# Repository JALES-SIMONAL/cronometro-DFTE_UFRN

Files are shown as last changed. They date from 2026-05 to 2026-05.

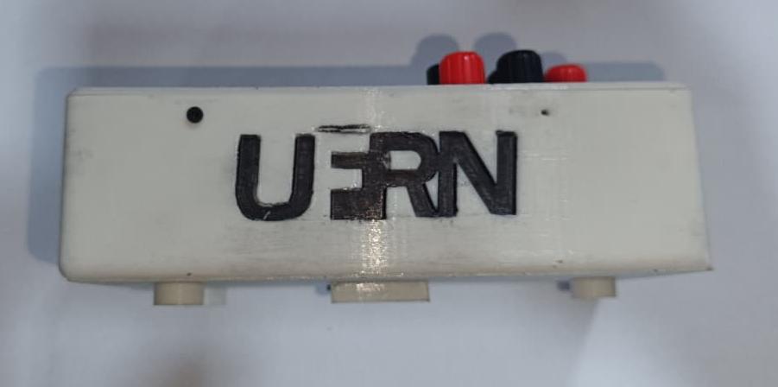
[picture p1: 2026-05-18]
Fotos/Hardware de aquisição de dados visão lateral.jpeg

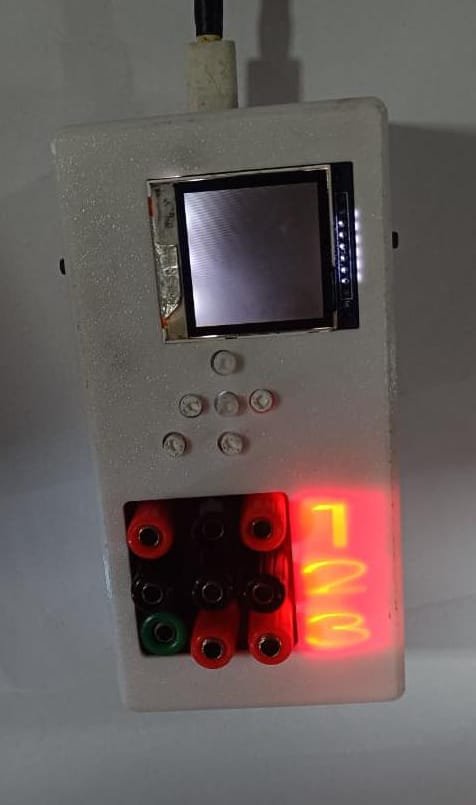
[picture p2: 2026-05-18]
Fotos/hardware de aquisição em modo de teste.jpeg

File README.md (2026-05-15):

# Cronômetro DFTE_UFRN

Este repositório contém um cronômetro digital de uso laboratorial, desenvolvido para o Departamento de Física Teórica e Experimental da UFRN. O projeto utiliza Arduino/ESP32, com o código principal em arquivo `.ino`, e peças impressas em 3D para montagem do gabinete.

---

## Principais características do arquivo .ino (Arduino/ESP32)

- **Linguagem/Compatibilidade**: Código em C++ próprio para Arduino, ESP32 ou similares.
- **Estrutura típica**:
    - Definição de pinos para botões, display, LEDs, etc.
    - Inicialização de periféricos no `setup()`.
    - Loop principal para leitura de botões e atualização do display.
    - Funções auxiliares para debounce, controle de estado, e lógica de contagem.
- **Operações suportadas:**
    - Iniciar, pausar e resetar o cronômetro.
    - Exibição precisa do tempo (até milissegundos, se desejado).
    - Indicação visual (LEDs, display) e sonora (se houver buzzer).
- **Flexível e comentado:** Fácil adaptação do código e documentação com comentários para aprendizado ou modificações.

---

## Lista de Componentes Eletrônicos

| Qtde | Descrição | Designador | Fabricante/Supplier | Parte/Fabricante | Código LCSC |
|---|---|---|---|---|---|
| 1 | ESP32 DEVKITV1 | - | - | ESP32-DEVKITV1 | - |
| 1 | Suporte p/ Bateria 18650 | U12 | - | BAT_BOX | C9900015078 |
| 1 | Regulador de Tensão | U4 | - | 134N3P COPY | - |
| 9 | Conector Banana (painel) | U1-U3, U6-U11 | - | Any Banana Jack | - |
| 1 | Conector 2P KH-PH-2P-Z | CN1 | kinghelm | KH-PH-2P-Z | C2898945 |
| 3 | Capacitor 0805 | C1, C2, C3 | - | - | - |
| 3 | LED RGB WS2812B-5050 | LED1-LED3 | - | WS2812B-5050RGB | C2838584 |
| 6 | Push button 6x6x7mm | KEY1-KEY6 | ReliaPro | 6*6*7 | C69055 |
| 1 | Módulo LCD 1.8" | LCD1 | Waveshare | 1.8INCH LCD MODULE | C359940 |
| 4 | MOSFET LBSS138LT1G-VB | Q1-Q4 | VBsemi | LBSS138LT1G-VB | C7429063 |
| 9 | Resistor 0805 10k | R1, R2-R9 | - | 0805_10k | C9900012714 |
| 1 | Chave CN-KCD1-101-2P | SW1 | - | CN-KCD1-101-2P | C9900002516 |

> Consulte a BOM completa para detalhes adicionais: `BOM_PhotoGate_Controlador_2026-05-15.csv`.

---

## Lista de Peças para Impressão 3D

1. **Gabinete Principal:** Estrutura para acomodar o ESP32, LCD, botões e conectores.
2. **Frontal do Gabinete:** Painel com janelas/furos para display, LEDs e botões.
3. **Tampa Traseira:** Fecho para o gabinete, com furos para fixação se necessário.
4. **Suporte para a bateria 18650:** (opcional, conforme design).
5. **Botões personalizados para painel:** (opcional, melhor ergonomia/estética).
6. **Bases ou pés para apoio:** (opcional, estabilidade em bancada).

> Os arquivos STL necessários para impressão estarão na pasta `/impressao_3d` deste repositório.

---

## Montagem e Funcionamento

1. **Imprima as peças 3D** conforme necessário.
2. **Monte o ESP32, display e botões** no gabinete impresso.
3. **Realize a ligação dos botões, display e LEDs** de acordo com o que está especificado no `.ino` e na tabela de componentes.
4. **Alimente o circuito** via USB ou bateria (18650, conforme montagem).
5. **Carregue e rode o código** na ESP32 usando a IDE Arduino.
6. **Operação**: utilize os botões para iniciar, pausar ou resetar. O tempo será mostrado no LCD, e LEDs poderão sinalizar o status.

---

## Recomendações e Observações

- Confirme o mapeamento dos pinos entre hardware e código.
- Use resistores de pull-down nos botões para evitar disparos falsos.
- Realize testes antes de fechar o gabinete definitivamente.
- Adapte o código caso utilize um display/módulo diferente.
- Instale quaisquer bibliotecas necessárias na IDE Arduino antes do upload.

---

## Licença

[uso livre]

---

**Dúvidas, sugestões ou problemas?**  
Abra uma issue neste repositório.

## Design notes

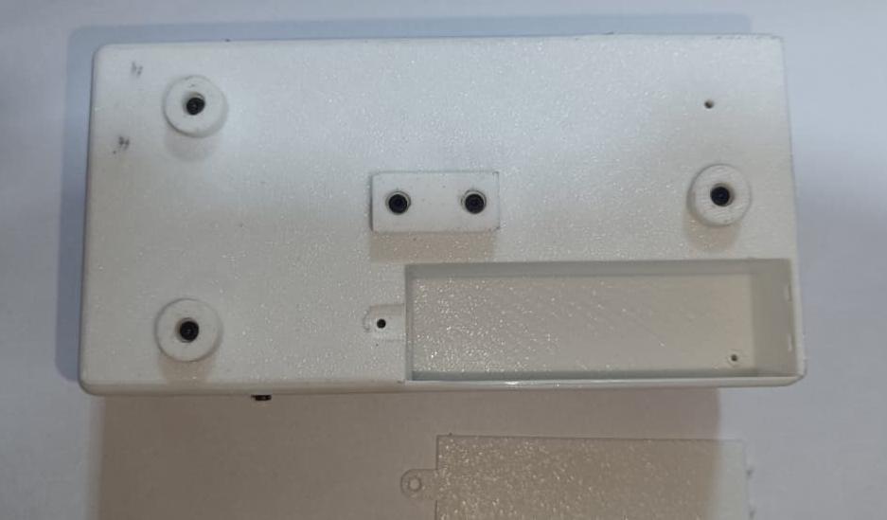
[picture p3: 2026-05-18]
Fotos/Hardware de aquisição de dados visão posterior.jpeg

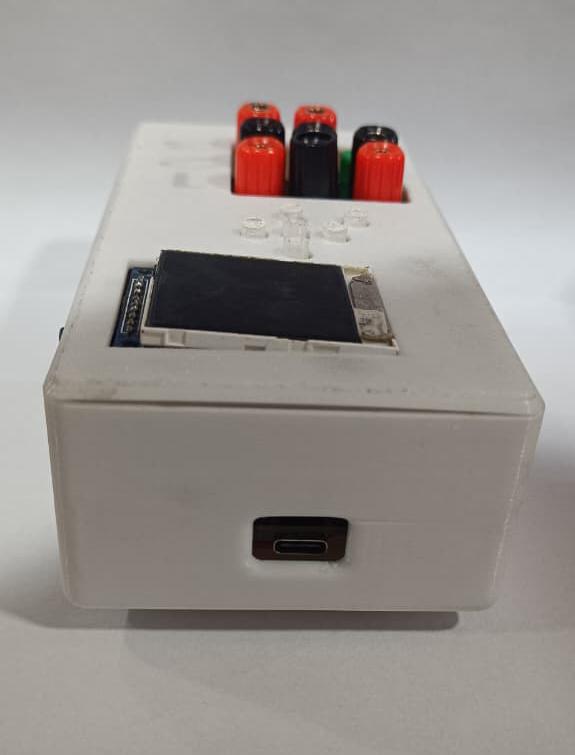
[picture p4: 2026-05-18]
Fotos/Hardware de aquisição de dados visão superior.jpeg

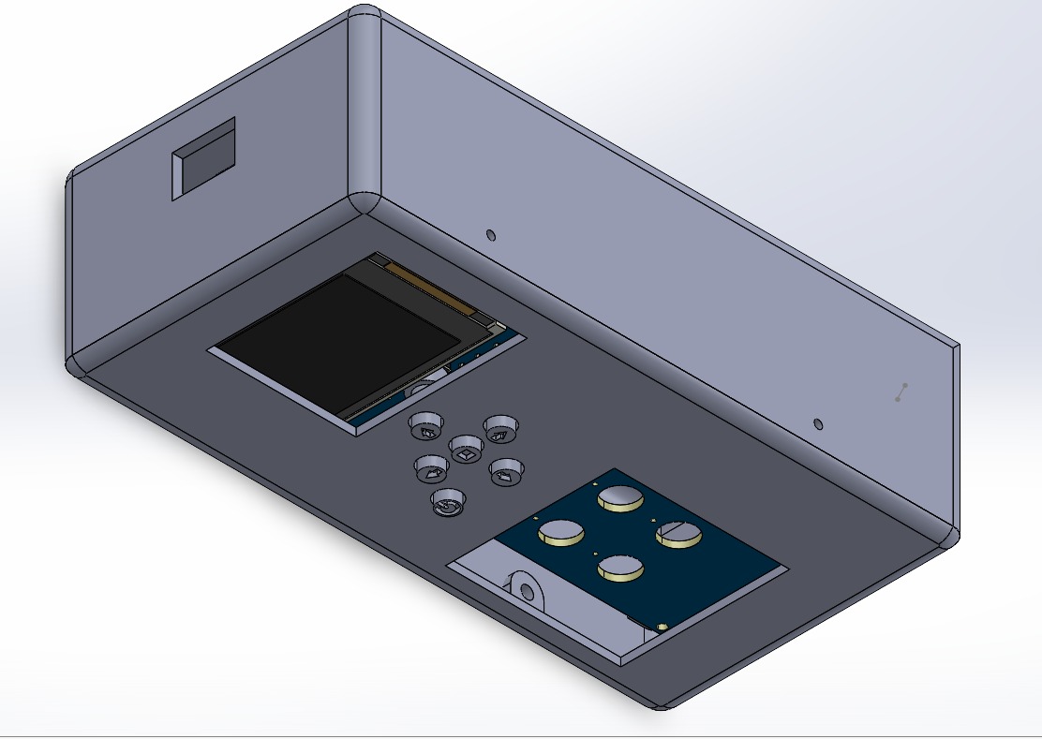
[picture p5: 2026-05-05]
Fotos/modelagem completa do hardware.jpeg

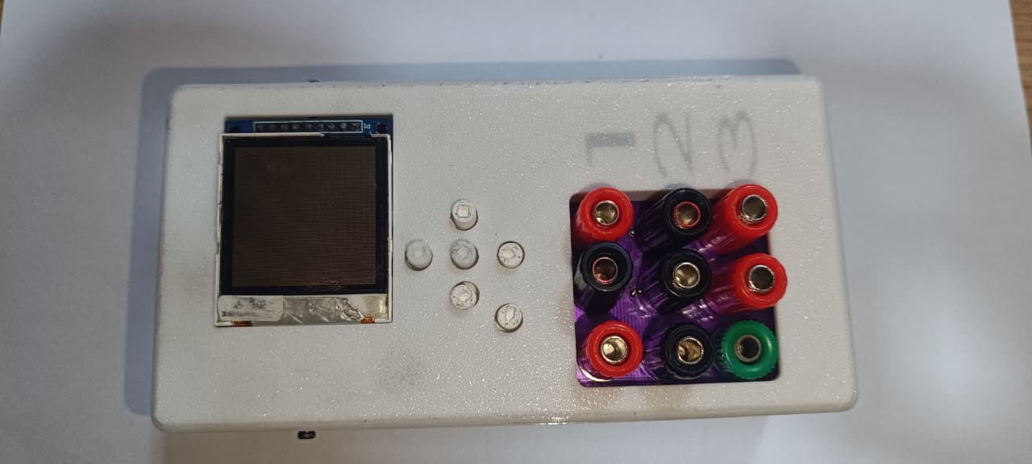
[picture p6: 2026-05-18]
Fotos/Hardware de aquisição de dados visão frontal.jpeg

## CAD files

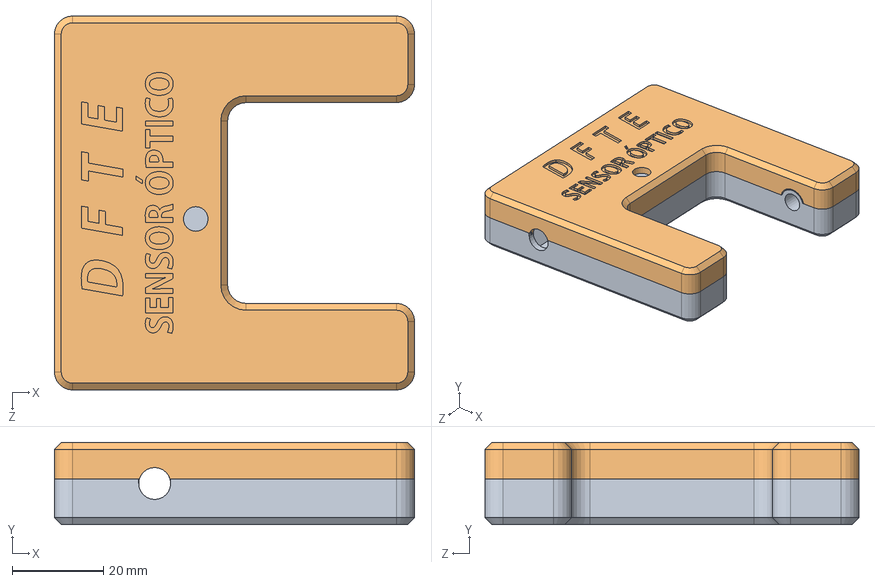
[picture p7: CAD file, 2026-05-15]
arquivos de Fabricação/Impressão_3D/Sensor/Montagem do Sensor.SLDASM
79.0 x 18.0 x 82.0 mm
Parte A - Case de Sensor
Parte B - Case de Sensor

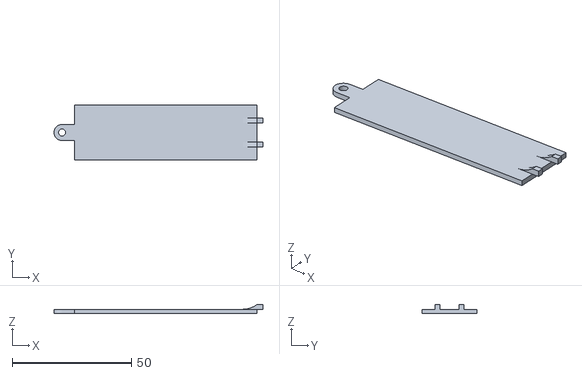
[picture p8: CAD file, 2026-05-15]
arquivos de Fabricação/Impressão_3D/Hardware de aquisição/arquivos_stl/tampa bateria.STL
87.6 x 23.0 x 3.74

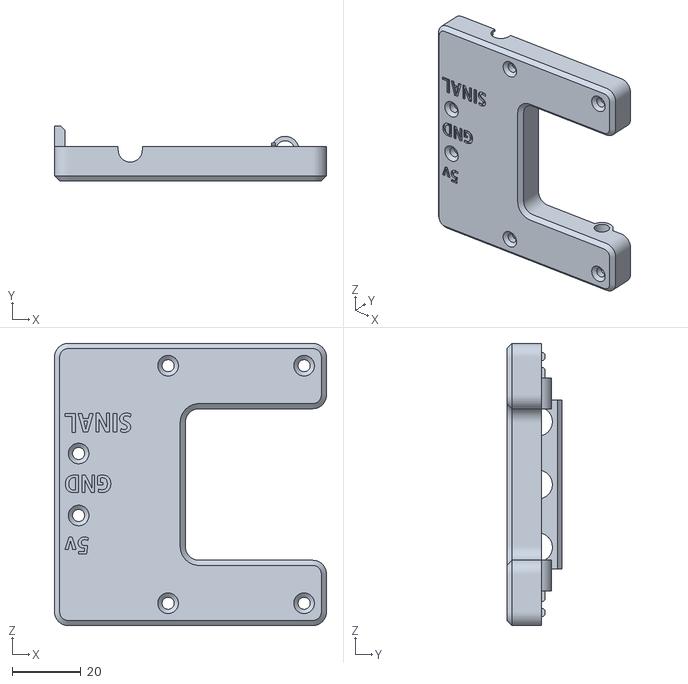
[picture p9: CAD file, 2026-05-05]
arquivos de Fabricação/Impressão_3D/Sensor/arquivos .stl/Parte B - Case de Sensor.STL
79.0 x 16.0 x 82.0

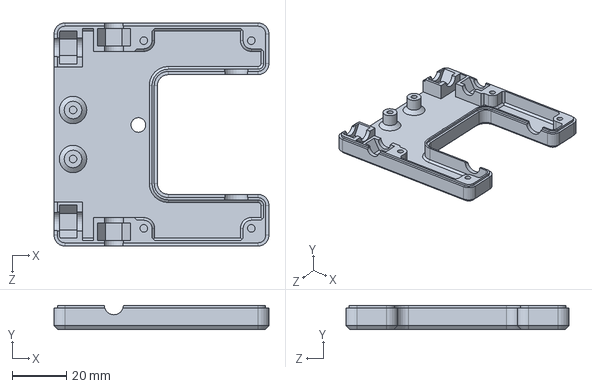
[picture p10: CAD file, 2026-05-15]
arquivos de Fabricação/Impressão_3D/Sensor/Parte A - Case de Sensor.SLDPRT
79.0 x 9.00 x 82.0 mm

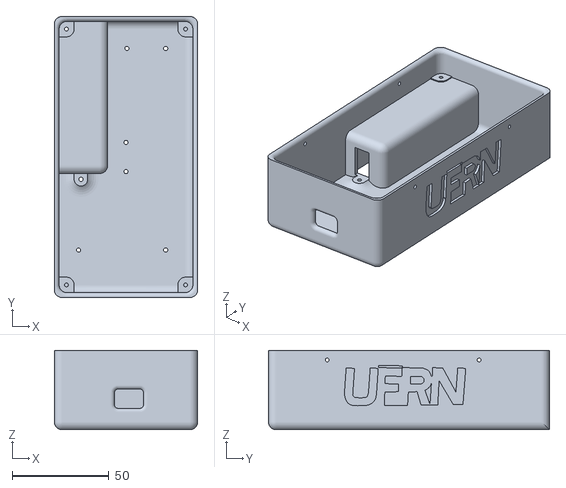
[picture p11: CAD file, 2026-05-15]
arquivos de Fabricação/Impressão_3D/Hardware de aquisição/arquivos_stl/case cronometro.STL
74.0 x 145.0 x 41.0

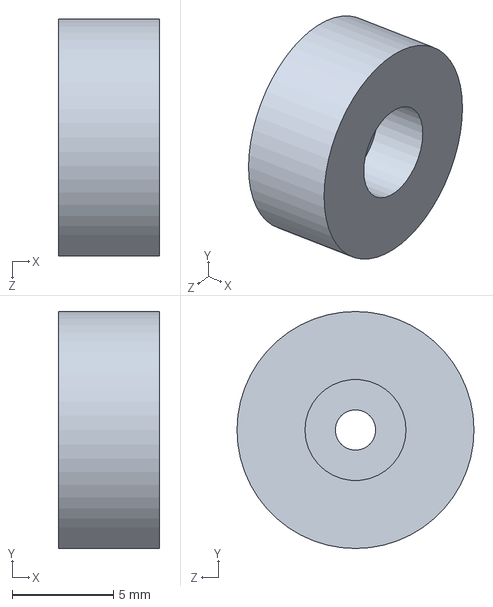
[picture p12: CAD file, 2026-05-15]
arquivos de Fabricação/Impressão_3D/Hardware de aquisição/pé.SLDPRT
5.00 x 11.7 x 11.7 mm

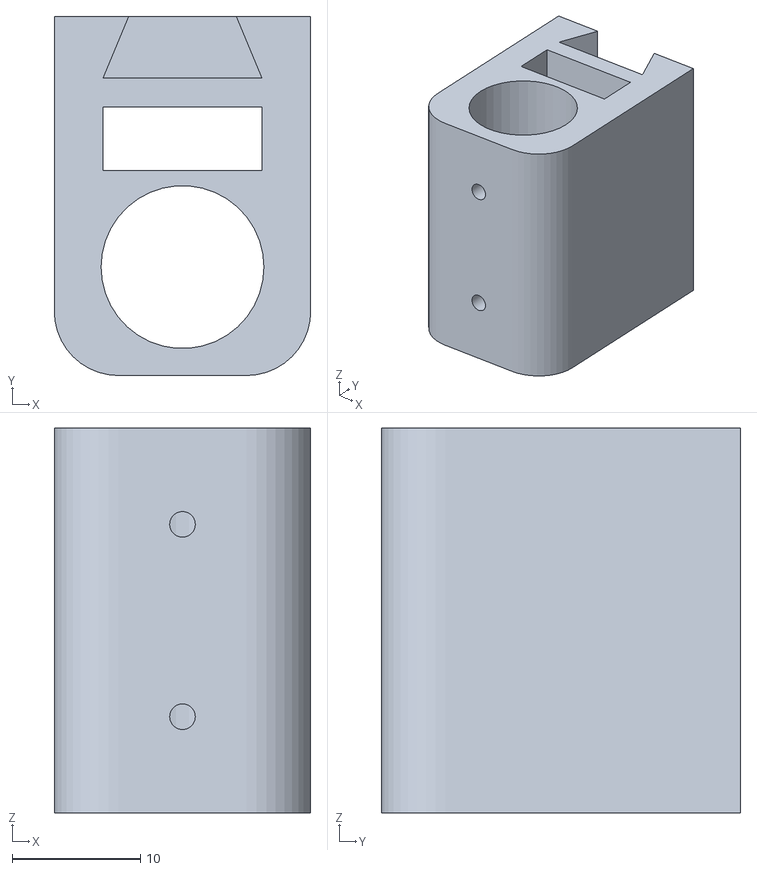
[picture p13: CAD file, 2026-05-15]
arquivos de Fabricação/Impressão_3D/Hardware de aquisição/arquivos_stl/fixador1.STL
20.0 x 28.0 x 30.0

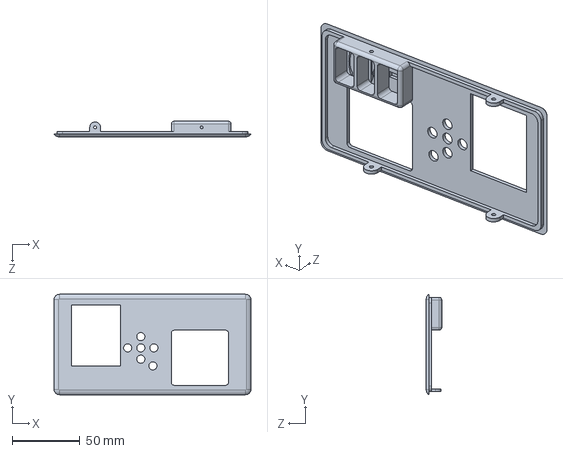
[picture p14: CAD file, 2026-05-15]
arquivos de Fabricação/Impressão_3D/Hardware de aquisição/tampa cronometro.SLDPRT
145.0 x 74.0 x 11.5 mm

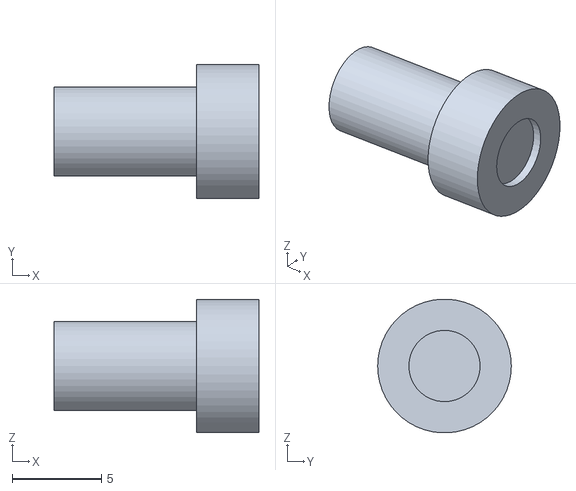
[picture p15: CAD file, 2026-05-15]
arquivos de Fabricação/Impressão_3D/Hardware de aquisição/arquivos_stl/botão central.STL
11.5 x 7.50 x 7.49

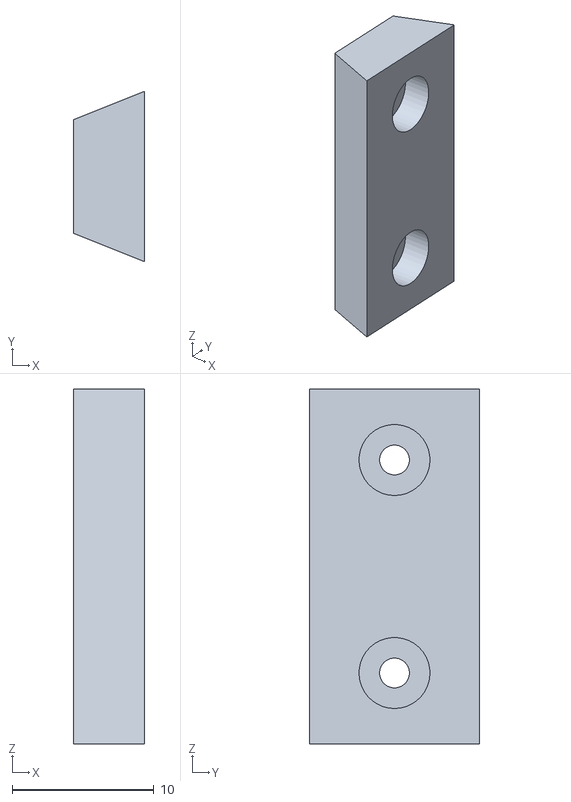
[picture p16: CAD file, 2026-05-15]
arquivos de Fabricação/Impressão_3D/Hardware de aquisição/arquivos_stl/encaixe.STL
5.00 x 12.0 x 25.0

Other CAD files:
arquivos de Fabricação/Impressão_3D/Hardware de aquisição/tampa bateria.SLDPRT
arquivos de Fabricação/Impressão_3D/Sensor/arquivos .stl/Parte A - Case de Sensor.STL
arquivos de Fabricação/Impressão_3D/Sensor/Parte B - Case de Sensor.SLDPRT
arquivos de Fabricação/Impressão_3D/Hardware de aquisição/botão.SLDPRT
arquivos de Fabricação/Impressão_3D/Hardware de aquisição/fixador.SLDPRT
arquivos de Fabricação/Impressão_3D/Hardware de aquisição/arquivos_stl/tampa cronometro.STL
arquivos de Fabricação/Impressão_3D/Hardware de aquisição/encaixe.SLDPRT
arquivos de Fabricação/Impressão_3D/Hardware de aquisição/arquivos_stl/pé.STL
arquivos de Fabricação/Impressão_3D/Hardware de aquisição/case cronometro.SLDPRT

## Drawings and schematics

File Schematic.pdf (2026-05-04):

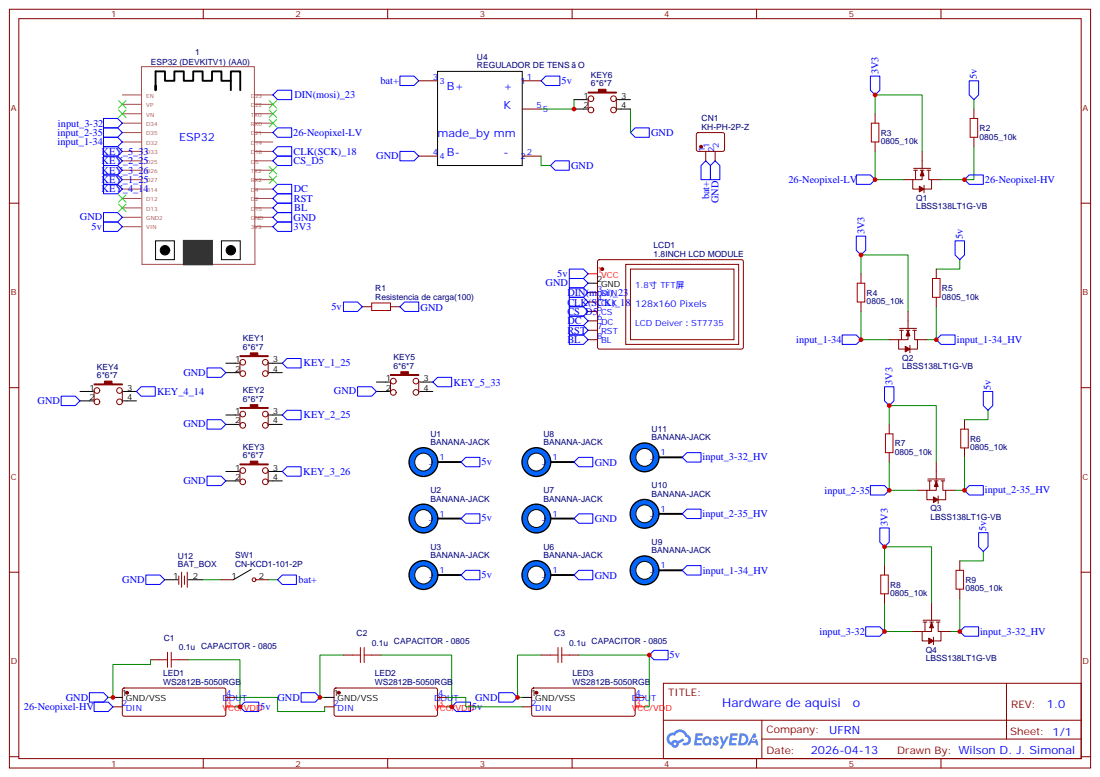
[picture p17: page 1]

Drawn By: Wilson D. J. Simonal

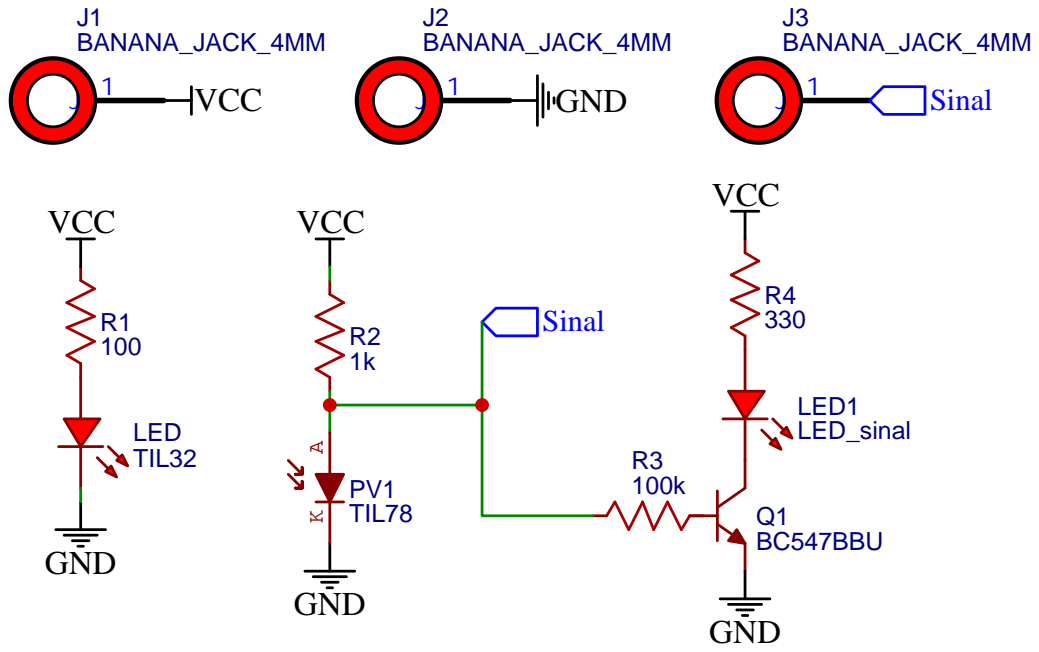
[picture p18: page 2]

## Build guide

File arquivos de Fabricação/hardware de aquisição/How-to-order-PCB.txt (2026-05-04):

How to Order PCB

Please refer to:
https://docs.easyeda.com/en/PCB/Order-PCB

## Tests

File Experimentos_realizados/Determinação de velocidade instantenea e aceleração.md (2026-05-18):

# Determinação de velocidade instantenea e aceleração
O presente experimento foi tem o objetivo de verificar a aceleração instantanea de um carro em 2 pontos sobre um trilho de ar( sem atrito).

## Descrição da montagem do experimento 

A [imagem](#layout) abaixo mostra a disposição da montagem. A montagem consiste em um trilho de ar com [inclinação de 5°](#medição_graus_inclinação) conectado a um soprador de ar. Na extremidade esquerda do trilho de ar, encontra-se um disparador mecânico manual, responsável por iniciar o movimento. Logo à frente do disparador mecânico se encontra o carro, que se movimentará de uma ponta a outra do trilho após o disparo. Sobre o carro, há uma vela com comprimento de [10 cm](#mediçãoVela), usada para calcular a velocidade instantânea nos dois pontos escolhidos. Os sensores *photogate* S1 e S2 usados são de [fabricação própria](#sensor) e foram posicionados respectivamente nas posições [140cm ](#s1_140) e [90cm](#s2_90). Os sensores *photogate* têm sua alimentação e seu sinal de resposta conectados ao hardware de aquisição de dados.

<br><br>
<div id="layout" align="center">
  bancada_teste_experimento
  <br>
  <em>Bancada de teste do experimento</em>
</div>

## medições dos tempos

### Velocidade Instantânea no Sensor S1

| $t_1$ (ms) | $t_2$ (ms) | $t_2 - t_1$ (ms) | Velocidade instantânea (m/s) |
| :---: | :---: | :---: | :---: |
| 3329 | 3425 | 96 | 1,041666667 |
| 4083 | 4176 | 93 | 1,075268817 |
| 4557 | 4650 | 93 | 1,075268817 |
| 4602 | 4700 | 98 | 1,020408163 |
| 4584 | 4682 | 98 | 1,020408163 |
| 4563 | 4657 | 94 | 1,063829787 |
| 2734 | 2832 | 98 | 1,020408163 |
| 3691 | 3788 | 97 | 1,030927835 |
| 2824 | 2919 | 95 | 1,052631579 |
| 5798 | 5898 | 100 | 1 |
| 1617 | 1706 | 89 | 1,123595506 |
| **Velocidade média em S1** | | | **1,15244135** |

### Velocidade Instantânea no Sensor S2

| $t_1$ (ms) | $t_2$ (ms) | $t_2 - t_1$ (ms) | Velocidade instantânea (m/s) |
| :---: | :---: | :---: | :---: |
| 3757 | 3832 | 75 | 1,333333333 |
| 4501 | 4575 | 74 | 1,351351351 |
| 4975 | 5049 | 74 | 1,351351351 |
| 5038 | 5115 | 77 | 1,298701299 |
| 5019 | 5095 | 76 | 1,315789474 |
| 4983 | 5058 | 75 | 1,333333333 |
| 3167 | 3243 | 76 | 1,315789474 |
| 3121 | 3197 | 76 | 1,315789474 |
| 3245 | 3320 | 75 | 1,333333333 |
| 6241 | 6318 | 77 | 1,298701299 |
| 2018 | 2089 | 71 | 1,408450704 |
| **Velocidade média em S2** | | | **1,465592443** |

## calculos

$$v_{s2}^2 = v_{s1}^2 + 2a\Delta s$$

$$a = \frac{v_{s2}^2 - v_{s1}^2}{2\Delta s}$$

$$a = \frac{1,465592^2 - 1,152441^2}{2 \cdot 0,5} = 0,819 \text{ m/s}^2$$

$$a = g \cdot \sin(\theta)$$

$$a = 9,81 \cdot \sin(5^\circ) \approx 0,854 \text{ m/s}^2$$

<br><br>

## Imagens das medições

<div id="medição_graus_inclinação" align="center">
  medicao_inclinacao
  <br>
  <em>Medição de inclinação, 5° de inclinação
</div>

<br><br>

<div id="mediçãoVela" align="center">
  medição_da_vela
  <br>
  <em>Medição da vela, comprimento de 10cm</em>
</div>

<br><br>

<div id="s1_140" align="center">
  posicao_sensor_s1
  <br>
  <em>Posição do sensor s1 140cm</em>
</div>

<br><br>

<div id="s2_90" align="center">
  posicao_sensor_s2
  <br>
  <em>Posição do sensor s2 90cm</em>
</div>

<br><br>

<div id="sensor" align="center">
  sensor_photogate_proprio
  <br>
  <em>sensor photogate de fabricação própria</em>
</div>

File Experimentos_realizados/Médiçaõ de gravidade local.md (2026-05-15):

## Descrição do experimento 

<p align="justify">
O experimento consistiu em um lançador de uma esfera metálica que, ao estar posicionada no dispositivo, fecha um circuito. Ao ser abandonada, a esfera abre o circuito, o que constitui o primeiro sinal de tempo ($t_1$). Imediatamente abaixo, e separado do lançador por uma distância $h$, fica o prato de captura da esfera. Ao pousar no prato, este se desloca para baixo, fechando outro circuito e gerando o segundo sinal de tempo ($t_2$). Para calcular a gravidade local, foi usada a fórmula descrita abaixo. A altura $h$ é definida pela distância entre os dois elementos de medição. O experimento foi realizado para três valores diferentes de $h$: 50 cm, 30 cm e 10 cm, sendo feitas 11 repetições para cada uma das medições. Vale salientar que os cálculos foram realizados utilizando as unidades do SI: metro para a distância e segundo para o tempo.
</p>

$$g = \frac{2h}{(t_2 - t_1)^2}$$

## Tabela de medições dos experimentos e valores de gravidade calculados

### Cálculo da Gravidade (Distância entre sensores h: 10 cm)

| $t_1$ (ms) | $t_2$ (ms) | $t_2 - t_1$ (ms) | $g$ (m/s²) |
| :---: | :---: | :---: | :---: |
| 880 | 1022 | 142 | 9,918667 |
| 925 | 1069 | 144 | 9,645062 |
| 549 | 691 | 142 | 9,918667 |
| 725 | 867 | 142 | 9,918667 |
| 590 | 733 | 143 | 9,780429 |
| 298 | 439 | 141 | 10,059860 |
| 381 | 523 | 142 | 9,918667 |
| 781 | 923 | 142 | 9,918667 |
| 388 | 529 | 141 | 10,059860 |
| 220 | 360 | 140 | 10,204082 |
| 591 | 735 | 144 | 9,645062 |
| **Aceleração Média** | | | **9,907971** |

### Cálculo da Gravidade (Distância entre sensores h: 30 cm)

| $t_1$ (ms) | $t_2$ (ms) | $t_2 - t_1$ (ms) | $g$ (m/s²) |
| :---: | :---: | :---: | :---: |
| 394 | 640 | 246 | 9,914733 |
| 401 | 648 | 247 | 9,834615 |
| 1001 | 1247 | 246 | 9,914733 |
| 2274 | 2519 | 245 | 9,995835 |
| 757 | 1001 | 244 | 10,077940 |
| 243 | 490 | 247 | 9,834615 |
| 671 | 916 | 245 | 9,995835 |
| 613 | 858 | 245 | 9,995835 |
| 651 | 899 | 248 | 9,755463 |
| 1840 | 2086 | 246 | 9,914733 |
| 1256 | 1501 | 245 | 9,995835 |
| **Aceleração Média** | | | **9,930015** |

### Cálculo da Gravidade (Distância entre sensores h: 50 cm)

| $t_1$ (ms) | $t_2$ (ms) | $t_2 - t_1$ (ms) | $g$ (m/s²) |
| :---: | :---: | :---: | :---: |
| 899 | 1217 | 318 | 9,888849333 |
| 3987 | 4305 | 318 | 9,888849333 |
| 1233 | 1552 | 319 | 9,826947455 |
| 459 | 778 | 319 | 9,826947455 |
| 652 | 970 | 318 | 9,888849333 |
| 551 | 870 | 319 | 9,826947455 |
| 793 | 1112 | 319 | 9,826947455 |
| 1040 | 1359 | 319 | 9,826947455 |
| 3151 | 3470 | 319 | 9,826947455 |
| 2697 | 3015 | 318 | 9,888849333 |
| 966 | 1284 | 318 | 9,888849333 |
| **Aceleração Média** | | | **9,855084673** |

## Seque a baixo algumas imagens do experimento 

<div align="center">
  Gravidade
  <br>
  <em>layout do experimento</em>
</div>

<br>
<br>

<div align="center">
  gravidade_10cm
  <br>
  <em>Ajuste de distância h para 10cm</em>
</div>

<br>
<br>

<div align="center">
  gravidade_30cm
  <br>
  <em>Ajuste de distância h para 30cm</em>
</div>

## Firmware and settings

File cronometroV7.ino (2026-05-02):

#include <WiFi.h>
#include <WebSocketsServer.h>
#include <ArduinoJson.h>
#include <WebServer.h>
#include <Adafruit_NeoPixel.h>
#include <EEPROM.h>

// ============================================================
//                       CONFIGURAÇÕES
// ============================================================
const char* WIFI_SSID = "CONTROLE_ESP32";
const char* WIFI_PASSWORD = "12345678";

#define BTN_UP 27
#define BTN_DOWN 25
#define BTN_OK 26
#define BTN_LEFT 33
#define BTN_RIGHT 14

const int SENSOR_1_PIN = 32;
const int SENSOR_2_PIN = 35;
const int SENSOR_3_PIN = 34;

#define PIN_NEO 21
#define NUM_LEDS 3
Adafruit_NeoPixel pixels(NUM_LEDS, PIN_NEO, NEO_GRB + NEO_KHZ800);

#define EEPROM_SIZE 4096

// ============================================================
//                    SISTEMA DE ARQUIVOS EEPROM
// ============================================================
#define STORAGE_MAGIC 0x31534645UL  // "EFS1"
#define STORAGE_VERSION 1

#define MAX_FILES 30
#define MAX_EVENT_RECORDS 250
#define MAX_CAPTURE_EVENTS 500
#define FILE_NAME_LEN 15

enum FileType : uint8_t {
  FILE_TYPE_CHRONO = 1,
  FILE_TYPE_COUNTER = 2
};

enum DetectMode : uint8_t {
  DETECT_RISING = 0,
  DETECT_FALLING = 1,
  DETECT_BOTH = 2
};

struct __attribute__((packed)) StorageHeader {
  uint32_t magic;
  uint8_t version;
  uint8_t sensorMode[3];
  uint8_t fileCount;
  uint16_t usedEvents;
  uint16_t nextChronoNumber;
  uint16_t nextCounterNumber;
  uint8_t reserved[3];
};

struct __attribute__((packed)) FileRecord {
  uint16_t id;
  uint8_t type; // 1=cronometro, 2=contador
  char name[16];
  uint32_t timestampSec;
  uint32_t durationMs;
  uint16_t eventStart;
  uint16_t eventCount;
  uint8_t reserved;
};

struct __attribute__((packed)) EventRecord {
  uint8_t sensor;      // 1..3
  uint32_t timestampMs;
  uint8_t estado;      // HIGH/LOW
  int32_t counterPulses; // para contador
};

static_assert(sizeof(StorageHeader) <= 32, "StorageHeader muito grande");
static_assert(sizeof(FileRecord) == 32, "FileRecord esperado em 32 bytes");
static_assert(sizeof(EventRecord) == 10, "EventRecord esperado em 10 bytes");

StorageHeader gStorage;
FileRecord gFiles[MAX_FILES];
EventRecord gEvents[MAX_EVENT_RECORDS];

const uint16_t EEPROM_ADDR_HEADER = 0;
const uint16_t EEPROM_ADDR_FILES = EEPROM_ADDR_HEADER + sizeof(StorageHeader);
const uint16_t EEPROM_ADDR_EVENTS = EEPROM_ADDR_FILES + sizeof(FileRecord) * MAX_FILES;

// ============================================================
//                       ESTADOS DO SISTEMA
// ============================================================
enum States {
  STATE_MENU = 0,
  STATE_CRONOMETRO = 1,
  STATE_CONTADOR = 2,
  STATE_ARQUIVOS = 3,
  STATE_CONFIG = 4,
  STATE_TESTE = 5,
  STATE_DADOS = 6
};

// ============================================================
//                    INSTÂNCIAS DE SERVIDOR
// ============================================================
WebServer server(80);
WebSocketsServer webSocket = WebSocketsServer(81);

// ============================================================
//                  VARIÁVEIS GLOBAIS DE EXECUÇÃO
// ============================================================
volatile int currentState = STATE_MENU;
volatile int menuSelection = 0;
volatile bool stateChanged = false;

// Cronômetro
volatile unsigned long chronoStartTime = 0;
volatile unsigned long chronoTime = 0;
volatile unsigned long chronoPausedTime = 0;
volatile bool chronoRunning = false;
volatile bool chronoActive = false;
String draftChronoName = "";

// Contador
volatile int counterValues[3] = {0, 0, 0};
#define counterValue (counterValues[0] + counterValues[1] + counterValues[2])
volatile bool counterActive = false;
volatile unsigned long counterStartTime = 0;
String draftCounterName = "";

// Captura de eventos em RAM (sessão atual)
EventRecord captureEvents[MAX_CAPTURE_EVENTS];
uint16_t captureEventCount = 0;

int prevSensor1 = LOW;
int prevSensor2 = LOW;
int prevSensor3 = LOW;

String lastWarning = "";

// Botões
struct Button {
  int pin;
  String command;
  bool pressed;
  unsigned long pressTime;
};

Button buttons[5] = {
  {BTN_UP, "up", false, 0},
  {BTN_DOWN, "down", false, 0},
  {BTN_OK, "ok", false, 0},
  {BTN_LEFT, "left", false, 0},
  {BTN_RIGHT, "right", false, 0}
};

const unsigned long MIN_PRESS_TIME = 30;
const unsigned long MAX_PRESS_TIME = 2000;

// LED flash não-bloqueante por sensor
uint8_t ledFlashState[NUM_LEDS] = {0, 0, 0};      // 0=idle, 1=on, 2=off
uint32_t ledFlashColor[NUM_LEDS] = {0, 0, 0};
uint8_t ledFlashCount[NUM_LEDS] = {0, 0, 0};      // ciclos on/off restantes
unsigned long ledFlashStart[NUM_LEDS] = {0, 0, 0};
uint16_t ledFlashDelayMs[NUM_LEDS] = {40, 40, 40};

// Navegação e sincronização por botões físicos
int configSelectedSensor = 0;
int selectedFileIndex = -1;
uint16_t selectedFileId = 0;
uint8_t lastClientCount = 0;
unsigned long noClientSinceMs = 0;
unsigned long counterElapsedMs = 0;

// ============================================================
//                    PROTÓTIPOS DE FUNÇÕES
// ============================================================
void initWiFi();
void initButtons();
void initServers();
void initSensors();
void initEEPROM();

void handleRoot();
void handleDownloadFile();
void handleWebSocketEvent(uint8_t num, WStype_t type, uint8_t* payload, size_t length);

void processCommand(const String& cmd);
void processJsonCommand(uint8_t num, const String& payload);
void handleMenuInput(const String& cmd);
void handleChronoInput(const String& cmd);
void handleContadorInput(const String& cmd);
void handleConfigInput(const String& cmd);
void handleFilesInput(const String& cmd);

void checkButtons();
void updateChrono();
void checkSensoresChrono();
void checkSensoresContador();
void updateLedFlashes();
void checkAutoResetOnDisconnect();
void resetSessionToMenuOnDisconnect();

void sendStateToClients();
void sendFilesList(uint8_t clientNum = 255);
void sendFileView(uint8_t clientNum, uint16_t fileId);
void sendInfoMessage(const String& msg, bool warning = false);

void turnOffAllLeds();
void setLEDColor(uint32_t color);
void piscarLED(int ledIndex, uint32_t color, int vezes, int delayMs);
void updateNeoPixelsFromSensors();

void changeState(States newState, int newMenuSelection = 0);
int readSensor1();
int readSensor2();
int readSensor3();

void controlarCronometro(bool iniciar);
void resetarCronometro();
void finalizarCronometro(const String& suggestedName);
void iniciarContador();
void finalizarContador(const String& suggestedName);

bool shouldRegisterByMode(int prevState, int currState, uint8_t mode);
void registerCaptureEvent(uint8_t sensor, uint32_t timestampMs, uint8_t estado, int32_t counterPulses);

void storageInitOrLoad();
void storageFactoryReset();
bool storageCommit();
uint16_t storageUsedBytes();
uint16_t storageFreeBytes();

String sanitizeFileName(const String& raw, const String& fallback);
String defaultFileName(uint8_t fileType);
int findFileIndexById(uint16_t id);

bool saveSessionFile(uint8_t fileType, const String& requestedName, uint32_t durationMs,
                     EventRecord* events, uint16_t eventCount, uint16_t& outFileId);
bool deleteFileById(uint16_t id);
bool renameFileById(uint16_t id, const String& newName);
String csvFromFile(const FileRecord& rec);
String fileTypeLabel(uint8_t type);
const char* detectModeLabel(uint8_t mode);

// ============================================================
//                      HTML EMBARCADO
// ============================================================
const char* HTML_PAGE = R"rawliteral(
<!DOCTYPE html>
<html lang="pt-BR">
<head>
  <meta charset="UTF-8" />
  <meta name="viewport" content="width=device-width, initial-scale=1.0" />
  <title>Controle ESP32</title>
  <style>
    :root {
      --bg1: #0f172a;
      --bg2: #111827;
      --card: #1f2937;
      --card2: #111827;
      --text: #e5e7eb;
      --muted: #9ca3af;
      --accent: #22d3ee;
      --accent2: #60a5fa;
      --ok: #22c55e;
      --warn: #f59e0b;
      --danger: #ef4444;
      --shadow: 0 10px 30px rgba(0,0,0,.35);
      --radius: 18px;
    }

    * { box-sizing: border-box; }
    html, body { width: 100%; height: 100%; margin: 0; }

    body {
      font-family: Inter, system-ui, -apple-system, Segoe UI, Roboto, Arial, sans-serif;
      color: var(--text);
      background: radial-gradient(circle at 10% 10%, #1e3a8a 0%, transparent 35%),
                  radial-gradient(circle at 90% 20%, #0e7490 0%, transparent 35%),
                  linear-gradient(140deg, var(--bg1), var(--bg2));
      display: flex;
      justify-content: center;
      align-items: center;
      padding: 10px;
      overflow: hidden;
    }

    .app {
      width: min(100%, 460px);
      height: min(100vh - 12px, 860px);
      border-radius: var(--radius);
      background: linear-gradient(180deg, rgba(255,255,255,.06), rgba(255,255,255,.02));
      border: 1px solid rgba(255,255,255,.12);
      box-shadow: var(--shadow);
      backdrop-filter: blur(7px);
      display: grid;
      grid-template-rows: auto 1fr auto;
      overflow: hidden;
    }

    .header {
      display: flex;
      justify-content: space-between;
      align-items: center;
      padding: 12px 14px;
      border-bottom: 1px solid rgba(255,255,255,.12);
      background: linear-gradient(90deg, rgba(34,211,238,.2), rgba(96,165,250,.15));
      font-weight: 700;
      letter-spacing: .3px;
    }

    .header small { color: var(--muted); font-weight: 600; }

    .content {
      overflow: auto;
      padding: 12px;
      height: 100%;
      /* espaço fixo para pad virtual sempre visível */
      max-height: calc(100vh - 220px);
    }

    .state { display: none; animation: fade .22s ease; }
    .state.show { display: block; }

    @keyframes fade {
      from { opacity: 0; transform: translateY(8px); }
      to { opacity: 1; transform: translateY(0); }
    }

    .grid-menu {
      display: grid;
      grid-template-columns: repeat(2, minmax(0, 1fr));
      gap: 10px;
    }

    .menu-item {
      border: 1px solid rgba(255,255,255,.12);
      background: linear-gradient(180deg, rgba(255,255,255,.06), rgba(255,255,255,.02));
      padding: 14px;
      border-radius: 14px;
      min-height: 84px;
      display: flex;
      flex-direction: column;
      justify-content: center;
      gap: 4px;
      cursor: pointer;
      transition: .2s ease;
      user-select: none;
    }

    .menu-item .icon { font-size: 22px; }
    .menu-item .title { font-weight: 700; }
    .menu-item .desc { color: var(--muted); font-size: 12px; }

    .menu-item.active, .menu-item:hover {
      transform: translateY(-2px);
      border-color: rgba(34,211,238,.75);
      box-shadow: 0 0 0 1px rgba(34,211,238,.3), 0 10px 24px rgba(34,211,238,.18);
    }

    .card {
      background: linear-gradient(180deg, rgba(255,255,255,.06), rgba(255,255,255,.02));
      border: 1px solid rgba(255,255,255,.1);
      border-radius: 14px;
      padding: 12px;
      margin-bottom: 10px;
    }

    .display-big {
      text-align: center;
      font-size: clamp(34px, 8vw, 54px);
      font-weight: 800;
      letter-spacing: 2px;
      margin: 8px 0;
      text-shadow: 0 0 24px rgba(96,165,250,.55);
    }

    .status {
      text-align: center;
      color: var(--muted);
      font-weight: 600;
      margin-bottom: 8px;
    }

    .row { display: flex; gap: 8px; flex-wrap: wrap; }
    .row > * { flex: 1; min-width: 120px; }

    .btn {
      border: 1px solid rgba(255,255,255,.16);
      background: linear-gradient(180deg, rgba(34,211,238,.2), rgba(34,211,238,.08));
      color: #ecfeff;
      border-radius: 10px;
      padding: 10px;
      font-weight: 700;
      cursor: pointer;
      transition: .15s ease;
    }

    .btn:hover { transform: translateY(-1px); box-shadow: 0 8px 18px rgba(34,211,238,.25); }
    .btn.warn { background: linear-gradient(180deg, rgba(245,158,11,.3), rgba(245,158,11,.12)); }
    .btn.danger { background: linear-gradient(180deg, rgba(239,68,68,.3), rgba(239,68,68,.12)); }
    .btn.ok { background: linear-gradient(180deg, rgba(34,197,94,.3), rgba(34,197,94,.12)); }

    input, select {
      width: 100%;
      border: 1px solid rgba(255,255,255,.14);
      border-radius: 10px;
      background: rgba(17,24,39,.8);
      color: var(--text);
      padding: 8px 10px;
      font-size: 14px;
      outline: none;
    }

    .kpi {
      display: grid;
      grid-template-columns: repeat(2, minmax(0, 1fr));
      gap: 10px;
    }

    .kpi .item {
      background: rgba(17,24,39,.55);
      border: 1px solid rgba(255,255,255,.1);
      border-radius: 12px;
      padding: 10px;
      font-size: 13px;
    }

    .kpi .item strong { display: block; font-size: 18px; margin-top: 3px; }

    .pill {
      display: inline-block;
      font-size: 12px;
      padding: 4px 8px;
      border-radius: 999px;
      border: 1px solid rgba(255,255,255,.14);
      background: rgba(17,24,39,.7);
      margin-right: 4px;
      margin-bottom: 4px;
    }

    .sensor-status-wrap {
      display: flex;
      gap: 14px;
      flex-wrap: wrap;
      margin-top: 8px;
    }
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
void loop() {
  server.handleClient();
  webSocket.loop();
  checkButtons();
  updateChrono();

  if (currentState == STATE_TESTE) {
    updateNeoPixelsFromSensors();
  }

  if (currentState == STATE_CRONOMETRO && chronoRunning) {
    checkSensoresChrono();
  }

  if (currentState == STATE_CONTADOR && counterActive) {
    checkSensoresContador();
  }

  updateLedFlashes();
  checkAutoResetOnDisconnect();

  static unsigned long lastPush = 0;
  if (millis() - lastPush > 120) {
    lastPush = millis();
    sendStateToClients();
  }

  yield();
}

// ============================================================
//                  INICIALIZAÇÕES DE HARDWARE
// ============================================================
void initEEPROM() {
  EEPROM.begin(EEPROM_SIZE);
  Serial.println("✓ EEPROM inicializada");
}

void initWiFi() {
  WiFi.mode(WIFI_AP);
  if (!WiFi.softAP(WIFI_SSID, WIFI_PASSWORD)) {
    Serial.println("✗ Falha ao iniciar AP");
    while (true) {
      yield();
    }
  }
  IPAddress localIP(192, 168, 4, 1);
  IPAddress gateway(192, 168, 4, 1);
  IPAddress subnet(255, 255, 255, 0);
  WiFi.softAPConfig(localIP, gateway, subnet);

  Serial.println("✓ Access Point ativo");
  Serial.println("SSID: " + String(WIFI_SSID));
  Serial.println("IP: " + WiFi.softAPIP().toString());
}

void initButtons() {
  for (int i = 0; i < 5; i++) {
    pinMode(buttons[i].pin, INPUT_PULLUP);
  }
  Serial.println("✓ Botões configurados");
}

void initSensors() {
  pinMode(SENSOR_1_PIN, INPUT);
  pinMode(SENSOR_2_PIN, INPUT);
  pinMode(SENSOR_3_PIN, INPUT);
  Serial.println("✓ Sensores configurados");
}

void initServers() {
  server.on("/", handleRoot);
  server.on("/download", handleDownloadFile);
  server.begin();

  webSocket.begin();
  webSocket.onEvent(handleWebSocketEvent);

  Serial.println("✓ WebServer na porta 80");
  Serial.println("✓ WebSocket na porta 81");
}

// ============================================================
//                     MANIPULADORES HTTP/WS
// ============================================================
void handleRoot() {
  server.send(200, "text/html; charset=utf-8", HTML_PAGE);
}

void handleDownloadFile() {
  if (!server.hasArg("id")) {
    server.send(400, "text/plain", "Parametro id obrigatorio");
    return;
  }

  uint16_t id = (uint16_t)server.arg("id").toInt();
  int idx = findFileIndexById(id);
  if (idx < 0) {
    server.send(404, "text/plain", "Arquivo nao encontrado");
    return;
  }

  String csv = csvFromFile(gFiles[idx]);
  String fileName = String(gFiles[idx].name) + ".csv";
  server.sendHeader("Content-Disposition", "attachment; filename=" + fileName);
  server.send(200, "text/csv; charset=utf-8", csv);
}

void handleWebSocketEvent(uint8_t num, WStype_t type, uint8_t* payload, size_t length) {
  switch (type) {
    case WStype_CONNECTED:
      Serial.printf("[WS %u] conectado\n", num);
      lastClientCount = webSocket.connectedClients();
      noClientSinceMs = 0;
      sendStateToClients();
      sendFilesList(num);
      break;

    case WStype_DISCONNECTED:
      Serial.printf("[WS %u] desconectado\n", num);
      lastClientCount = webSocket.connectedClients();
      if (lastClientCount == 0) {
        noClientSinceMs = millis();
      }
      break;

    case WStype_TEXT: {
      String msg = String((char*)payload).substring(0, length);
      msg.trim();
      if (msg.length() == 0) return;

      if (msg[0] == '{') {
        processJsonCommand(num, msg);
      } else {
        if (msg == "up" || msg == "down" || msg == "left" || msg == "right" || msg == "ok") {
          processCommand(msg);
        }
      }
      break;
    }

    default:
      break;
  }
}

void processJsonCommand(uint8_t num, const String& payload) {
  DynamicJsonDocument doc(1024);
  auto err = deserializeJson(doc, payload);
  if (err) {
    sendInfoMessage("JSON invalido", true);
    return;
  }

  String action = doc["action"] | "";

  if (action == "menu_select") {
    menuSelection = constrain((int)(doc["index"] | 0), 0, 5);
    stateChanged = true;
    return;
  }

  if (action == "set_draft_name") {
    String target = doc["target"] | "";
    String name = doc["name"] | "";
    if (target == "chrono") draftChronoName = sanitizeFileName(name, "");
    if (target == "counter") draftCounterName = sanitizeFileName(name, "");
    return;
  }

  if (action == "finalize_chrono") {
    String name = doc["name"] | "";
    finalizarCronometro(name);
    return;
  }

  if (action == "finalize_counter") {
    String name = doc["name"] | "";
    finalizarContador(name);
    return;
  }

  if (action == "set_sensor_mode") {
    int sensor = doc["sensor"] | 0;
    int mode = doc["mode"] | 2;
    if (sensor >= 1 && sensor <= 3) {
      uint8_t normalized = (uint8_t)constrain(mode, 0, 2);
      gStorage.sensorMode[sensor - 1] = normalized;
      Serial.printf("[CONFIG] S%d modo temporário => %u (%s)\n", sensor, normalized, detectModeLabel(normalized));
      stateChanged = true;
    }
    return;
  }

  if (action == "save_sensor_config") {
    Serial.printf("[CONFIG] Salvando EEPROM S1=%u(%s) S2=%u(%s) S3=%u(%s)\n",
                  gStorage.sensorMode[0], detectModeLabel(gStorage.sensorMode[0]),
                  gStorage.sensorMode[1], detectModeLabel(gStorage.sensorMode[1]),
                  gStorage.sensorMode[2], detectModeLabel(gStorage.sensorMode[2]));
    if (storageCommit()) {
      sendInfoMessage("Configuração de sensores salva na EEPROM");
    }
    return;
  }

  if (action == "list_files") {
    sendFilesList(num);
    return;
  }

  if (action == "view_file") {
    uint16_t id = (uint16_t)(doc["id"] | 0);
    sendFileView(num, id);
    return;
  }

  if (action == "delete_file") {
    uint16_t id = (uint16_t)(doc["id"] | 0);
    if (deleteFileById(id)) {
      sendInfoMessage("Arquivo excluído");
      sendFilesList();
    }
    return;
  }

  if (action == "rename_file") {
    uint16_t id = (uint16_t)(doc["id"] | 0);
    String newName = doc["name"] | "";
    if (renameFileById(id, newName)) {
      sendInfoMessage("Arquivo renomeado");
      sendFilesList();
    }
    return;
  }
}

// ============================================================
//                          ESTADOS
// ============================================================
void changeState(States newState, int newMenuSelection) {
  // Requisito: sempre desligar LEDs em TODA transição de estado
  turnOffAllLeds();

  if (newState != STATE_ARQUIVOS) {
    selectedFileIndex = -1;
    selectedFileId = 0;
  } else if (gStorage.fileCount > 0) {
    if (selectedFileIndex < 0 || selectedFileIndex >= gStorage.fileCount) {
      selectedFileIndex = 0;
    }
    selectedFileId = gFiles[selectedFileIndex].id;
  }

  currentState = newState;
  menuSelection = newMenuSelection;
  stateChanged = true;

  Serial.printf("[STATE] -> %d\n", currentState);
}

void processCommand(const String& cmd) {
  if (currentState == STATE_MENU) {
    handleMenuInput(cmd);
  } else if (currentState == STATE_CRONOMETRO) {
    handleChronoInput(cmd);
  } else if (currentState == STATE_CONTADOR) {
    handleContadorInput(cmd);
  } else if (currentState == STATE_CONFIG) {
    handleConfigInput(cmd);
  } else if (currentState == STATE_ARQUIVOS) {
    handleFilesInput(cmd);
  } else if (currentState == STATE_DADOS || currentState == STATE_TESTE) {
    if (cmd == "left") {
      changeState(STATE_MENU, 0);
    }
  }
}

void handleMenuInput(const String& cmd) {
  if (cmd == "up") {
    menuSelection--;
    if (menuSelection < 0) menuSelection = 5;
  } else if (cmd == "down") {
    menuSelection++;
    if (menuSelection > 5) menuSelection = 0;
  } else if (cmd == "ok") {
    switch (menuSelection) {
      case 0:
        captureEventCount = 0;
        draftChronoName = "";
        resetarCronometro();
        changeState(STATE_CRONOMETRO, 0);
        break;
      case 1:
        iniciarContador();
        draftCounterName = "";
        changeState(STATE_CONTADOR, 1);
        break;
      case 2:
        changeState(STATE_ARQUIVOS, 2);
        selectedFileIndex = (gStorage.fileCount > 0) ? 0 : -1;
        selectedFileId = (selectedFileIndex >= 0) ? gFiles[selectedFileIndex].id : 0;
        sendFilesList();
        break;
      case 3:
        configSelectedSensor = 0;
        changeState(STATE_CONFIG, 3);
        break;
      case 4:
        changeState(STATE_TESTE, 4);
        break;
      case 5:
        changeState(STATE_DADOS, 5);
        break;
    }
  }
  stateChanged = true;
}
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

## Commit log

2026-05-04 Rename Schematic_PhotoGate_Controlador_2026-05-04 (2).pdf to Schematic.pdf
2026-05-04 Aquivos de fabricação
    [Drill_NPTH_Through.DRL, Drill_PTH_Through.DRL, Drill_PTH_Through_Via.DRL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]
2026-05-04 Create arquivos de fabricação do hardware de aquisição
2026-05-05 Rename Captura de tela 2026-05-04 205656.png to Projeto 3D da PCB frontal
2026-05-05 Rename Captura de tela 2026-05-04 205741.png to Projeto 3D parte posterior
2026-05-15 Peças para impressão do hardware de aquisição
    A motagem completa inclui
    5x botão
    1x tampa bateria
    1x tampa cronometro ( para visibilidade dos números é recomendado que seja impresso em branco)
    1x case cronometro
    4x pé
    1x fixador
    1x encaixe
    [botão.SLDPRT, case cronometro.SLDPRT, encaixe.SLDPRT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]
2026-05-15 lista para impressão
    Added a complete assembly list for 3D printing hardware.
2026-05-15 Add README with project overview and instructions
    Added a README file with project details, features, components, assembly instructions, and recommendations for the digital stopwatch developed for the UFRN Department of Theoretical and Experimental 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
2026-05-15 Create Médiçaõ de gravidade local
2026-05-16 Enhance experiment documentation with images
    Added images and details for the experiment on instantaneous velocity and acceleration.
2026-05-18 Aprimorar a descrição do experimento de aceleração
    Corrigido erros de digitação e gramática na descrição do experimento.
